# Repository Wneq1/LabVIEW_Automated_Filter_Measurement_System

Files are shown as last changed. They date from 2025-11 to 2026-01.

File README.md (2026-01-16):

# LabVIEW_Automated_Filter_Measurement_System

## 📋 Opis projektu
Projekt przedstawia system do zautomatyzowanego pomiaru charakterystyk częstotliwościowych filtrów aktywnych. Sercem układu jest autorska płytka PCB zaprojektowana w programie **KiCad**, zawierająca 6 różnych wariantów filtrów analogowych. System został stworzony z myślą o współpracy z aplikacją pomiarową w środowisku **LabVIEW**, co pozwala na automatyczne wykreślanie charakterystyk amplitodowo-fazowych.

## 🛠️ Architektura Sprzętowa (Hardware)

### 1. Sekcja Filtrów (Topologia Sallen-Key)
Na płytce znajduje się 6 filtrów aktywnych drugiego rzędu (2nd order). Wykorzystanie różnych wartości dobroci ($Q$) pozwala na demonstrację trzech klasycznych aproksymacji:

* **Bufory wejściowe (Wtórniki):** Zapewniają wysoką impedancję wejściową, eliminując wpływ impedancji źródła na parametry filtracji.
* **Filtry Dolnoprzepustowe (LPF) i Górnoprzepustowe (HPF):**
    * **$Q = 0.5$ (Bessel):** Filtr o najlepszej odpowiedzi impulsowej (brak przeregulowań) i liniowej fazie. Idealny do sygnałów prostokątnych i impulsowych.
    * **$Q = 0.707$ (Butterworth):** Filtr o maksymalnie płaskiej charakterystyce amplitudowej w paśmie przepustowym. Stanowi kompromis między szybkością opadania a odpowiedzią czasową.
    * **$Q = 2.0$ (Czebyszew):** Filtr o bardzo stromym zboczu opadania, ale kosztem pojawienia się pofalowań (ripple) i wzmocnienia w okolicy częstotliwości odcięcia.



Wybór konkretnej charakterystyki odbywa się poprzez przepięcie zworki na selektorze wyjściowym, co pozwala na natychmiastowe porównanie różnic w sygnale na oscyloskopie lub w programie LabVIEW.

### 2. Sekcja Filtrów Górnoprzepustowych (High-Pass)
Sekcja ta służy do tłumienia składowych o niskich częstotliwościach i przepuszczania sygnałów powyżej częstotliwości odcięcia ($f_c$). Zastosowano topologię Sallen-Key 2. rzędu, co pozwala na demonstrację wpływu dobroci ($Q$) na kształt "kolana" charakterystyki:

* **$Q = 0.5$ (Bessel )** 
* **$Q = 0.707$ (Butterworth)**
* **$Q = 2.0$ (Czebyszew)** 
     


### Porównanie parametrów konstrukcyjnych (HPF)
Wszystkie filtry oparte są na wzmacniaczu **OP07**, a różne typy odpowiedzi uzyskano poprzez precyzyjny dobór elementów biernych (zgodnie ze schematem):
* Kondensatory wejściowe (np. $C_{17}$, $C_{18}$) o wartości $10nF$.
* Rezystory ustalające dobroć (np. $R_{13} = 22k\Omega$, $R_{14} = 11k\Omega$).
### 3. Sekcja Zasilania (Power Supply)
Układ posiada zaawansowany blok zasilania, który umożliwia pracę z sygnałem zmiennym dzięki zasilaniu symetrycznemu:
* **Przetwornica DC-DC:** Użycie modułu **MGJ2D051515SC** pozwala na uzyskanie izolowanego napięcia symetrycznego $\pm 5V$  z pojedynczego wejścia DC.
* **Filtrowanie LC:** Zastosowanie dławika $L_1$ oraz kondensatorów $C_3$, $C_4$ minimalizuje tętnienia napięcia z przetwornicy impulsowej.
* **Zabezpieczenia:** Dioda chroniąca przed odwrotną polaryzacją oraz diody LED sygnalizujące obecność napięcia na szynach dodatniej i ujemnej.
* 


### 4. Schemat całego układu



## 🎨 Galeria Projektu i Wizualizacja PCB

W tej sekcji przedstawiono fizyczną strukturę projektu oraz finalny wygląd urządzenia po montażu. Projekt został zoptymalizowany pod kątem minimalizacji szumów oraz przejrzystości serwisowej.

### 1. Wizualizacja 3D (Render)
Dzięki narzędziom programu KiCad, wygenerowano realistyczny model 3D płytki **Active Filters Test Board**.
* **Layout:** Komponenty zostały rozmieszczone blokowo, co ułatwia diagnostykę sygnału od wejścia (Input) do wyjścia (Output).
* **Oznaczenia:** Na warstwie opisowej (silkscreen) umieszczono logotypy Politechniki Rzeszowskiej oraz KMiSD, a także czytelne etykiety dla zworek selekcyjnych dobroci $Q$.
* **Montaż:** Wykorzystano mieszaną technologię montażu (SMT dla układów scalonych i rezystorów, THT dla kondensatorów i złączy), co zapewnia kompromis między miniaturyzacją a łatwością modyfikacji.
  


### 2. Widok Warstwy Górnej (Top Layer)
Warstwa górna odpowiada głównie za prowadzenie sygnałów o wysokiej impedancji oraz zasilania wzmacniaczy operacyjnych:
* **Separacja Sygnałów:** Ścieżki sygnałowe są prowadzone w sposób możliwie najkrótszy, aby uniknąć zbierania zakłóceń elektromagnetycznych (EMI).
* **Blok Zasilania:** Wyraźnie wydzielona sekcja z przetwornicą **MGJ2D051515SC** i filtrem LC, która zasila całą płytkę napięciem symetrycznym $\pm 5V$.
* **Pola Masowe:** Wolne przestrzenie zostały wypełnione wylewką masy (Ground Plane), co poprawia stabilność pracy filtrów o wysokiej dobroci $Q=2.0$.
  


### 3. Widok Warstwy Dolnej (Bottom Layer)
Warstwa dolna pełni kluczową rolę w zapewnieniu integralności sygnałowej:
* **Ekranowanie:** Ciągła płaszczyzna masy na dolnej warstwie minimalizuje pętle masy i redukuje szumy przenoszone z sekcji zasilania impulsowego do czułych sekcji filtrów analogowych.
* **Przelotki (Vias):** Strategicznie rozmieszczone przelotki zapewniają niską impedancję połączeń między warstwami zasilania.
  


## 💻 Integracja z LabVIEW
W przyszłości projekt zostanie rozbudowy o automatyzacjie. Program w LabVIEW będzie obejmował:
1.  Sterowanie generatorem sygnałowym (częstotliwość sweep).
2.  Akwizycję danych przez kartę DAQ lub oscyloskop.
3.  Przetwarzanie danych i wizualizację charakterystyki amplitudowo-częstotliwościowej w czasie rzeczywistym.

## 🗂️ Struktura Repozytorium
* `/KiCad` - Pliki projektu PCB (schemat, layout, biblioteki).
* `/LabVIEW` - Pliki źródłowe programu pomiarowego (.vi).
* `/Documentation` - Dokumentacja techniczna i obliczenia filtrów.

---
*Projekt zrealizowany na Politechnice Rzeszowskiej (Katedra Metrologii i Systemów Diagnostycznych).*

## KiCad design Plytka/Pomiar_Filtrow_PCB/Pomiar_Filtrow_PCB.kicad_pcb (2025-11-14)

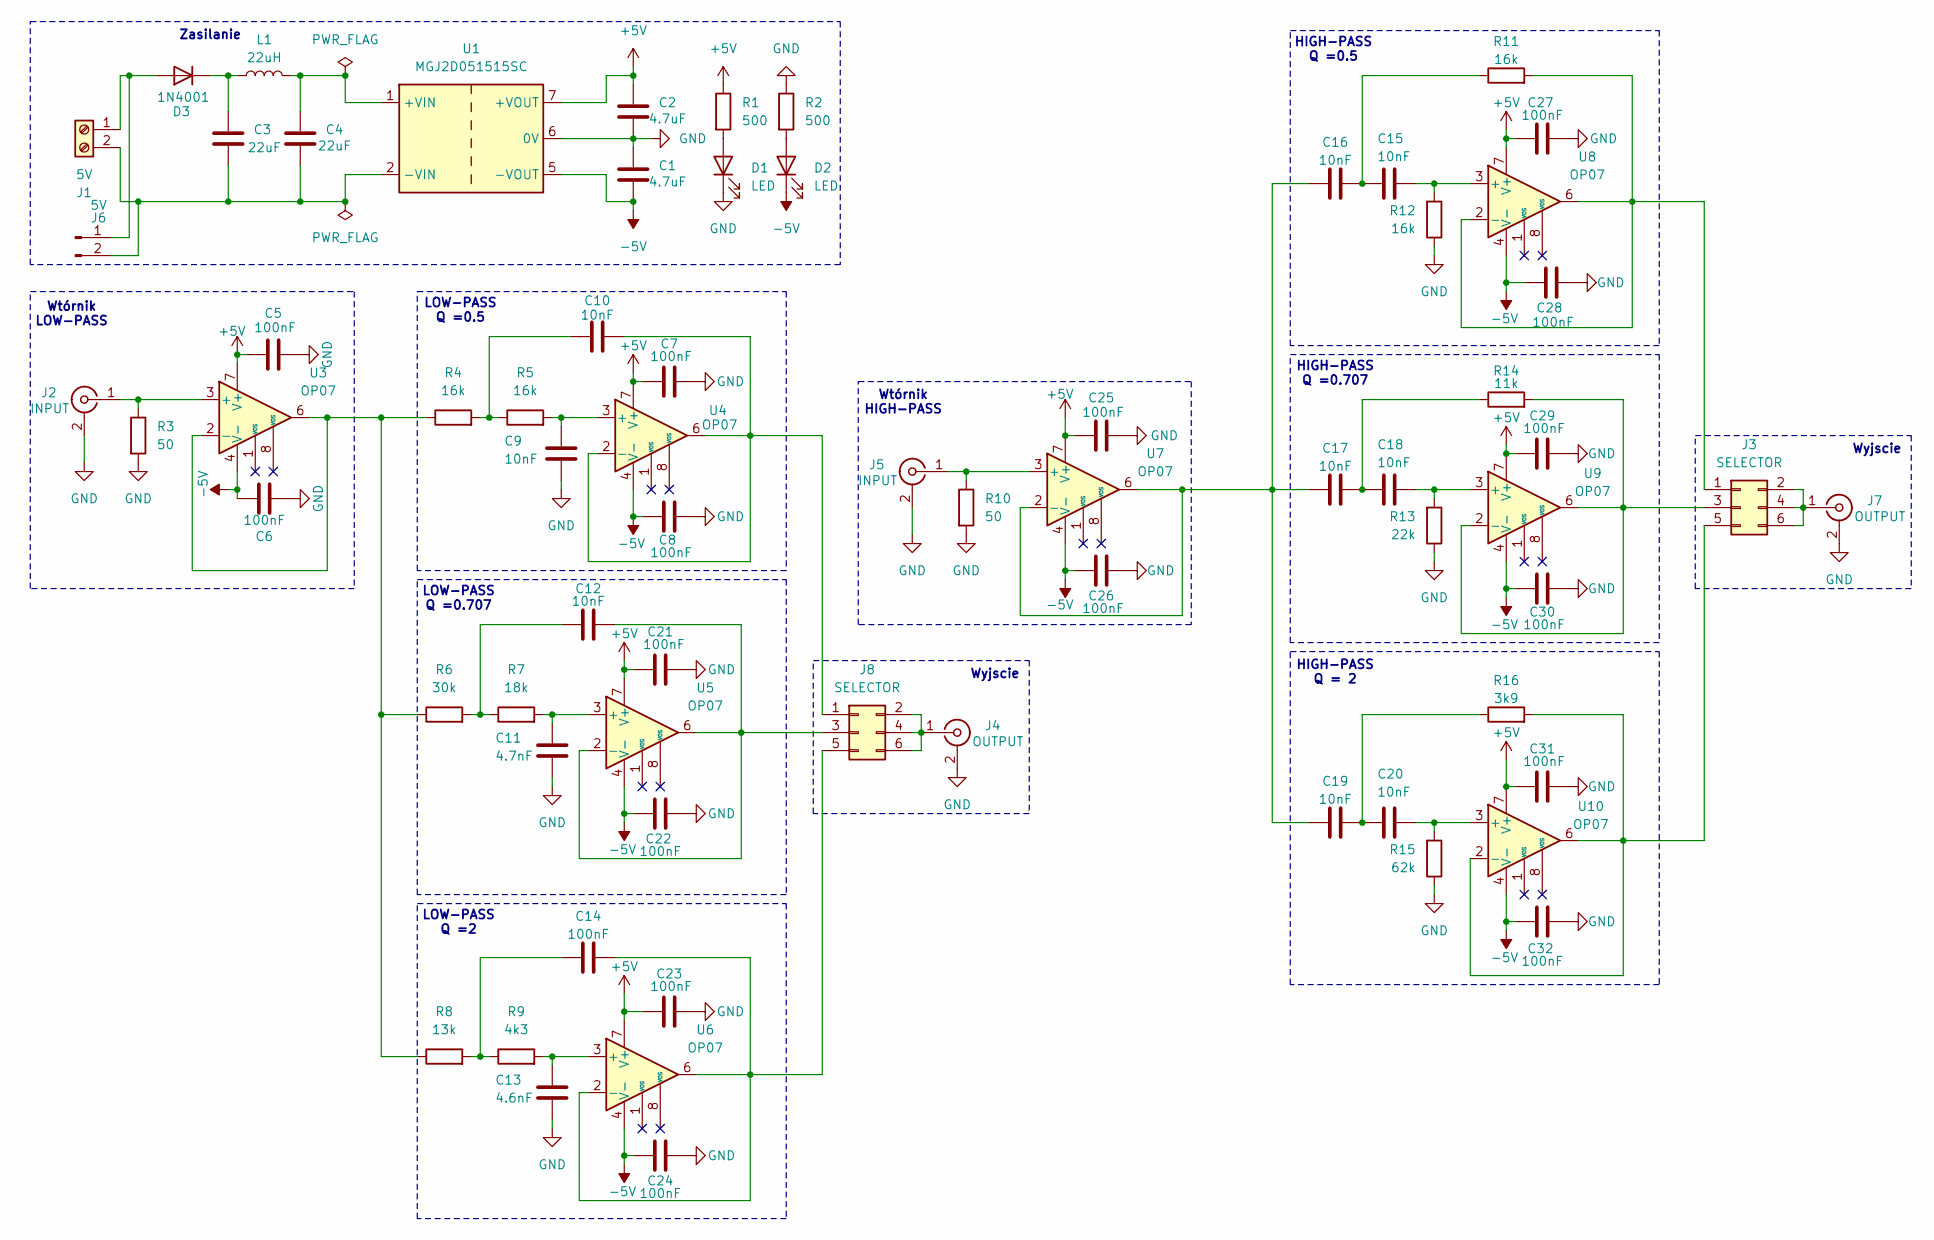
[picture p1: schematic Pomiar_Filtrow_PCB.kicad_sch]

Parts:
C1, C2: 4.7uF; C_Disc_D5.1mm_W3.2mm_P5.00mm
C3, C4: 22uF; C_Disc_D5.1mm_W3.2mm_P5.00mm
C5, C6, C7, C8, C14, C21, C22, C23, C24, C25, C26, C27, C28, C29, C30, C31, C32: 100nF; C_Disc_D5.1mm_W3.2mm_P5.00mm
C9, C10, C12, C15, C16, C17, C18, C19, C20: 10nF; C_Disc_D5.1mm_W3.2mm_P5.00mm
C11: 4.7nF; C_Disc_D5.1mm_W3.2mm_P5.00mm
C13: 4.6nF; C_Disc_D5.1mm_W3.2mm_P5.00mm
D1, D2: LED; LED_D3.0mm_FlatTop
D3: 1N4001; D_DO-41_SOD81_P10.16mm_Horizontal
J1: 5V; BarrelJack_GCT_DCJ200-10-A_Horizontal
J2, J5: INPUT; BNC_Amphenol_B6252HB-NPP3G-50_Horizontal
J3, J8: SELECTOR; PinHeader_2x03_P2.54mm_Vertical
J4, J7: OUTPUT; BNC_Amphenol_B6252HB-NPP3G-50_Horizontal
J6: 5V; PinHeader_1x02_P2.54mm_Vertical
L1: 22uH; L_Axial_L5.3mm_D2.2mm_P10.16mm_Horizontal_Vishay_IM-1
R1, R2: 500; R_1206_3216Metric_Pad1.30x1.75mm_HandSolder
R3, R10: 50; R_1206_3216Metric_Pad1.30x1.75mm_HandSolder
R4, R5, R11, R12: 16k; R_1206_3216Metric_Pad1.30x1.75mm_HandSolder
R6: 30k; R_1206_3216Metric_Pad1.30x1.75mm_HandSolder
R7: 18k; R_1206_3216Metric_Pad1.30x1.75mm_HandSolder
R8: 13k; R_1206_3216Metric_Pad1.30x1.75mm_HandSolder
R9: 4k3; R_1206_3216Metric_Pad1.30x1.75mm_HandSolder
R13: 22k; R_1206_3216Metric_Pad1.30x1.75mm_HandSolder
R14: 11k; R_1206_3216Metric_Pad1.30x1.75mm_HandSolder
R15: 62k; R_1206_3216Metric_Pad1.30x1.75mm_HandSolder
R16: 3k9; R_1206_3216Metric_Pad1.30x1.75mm_HandSolder
U1: MGJ2D051515SC; Converter_DCDC_Murata_MGJ2DxxxxxxSC_THT
U3, U4, U5, U6, U7, U8, U9, U10: OP07; SO-8_5.3x6.2mm_P1.27mm

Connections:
+5V: C2.2, C5.2, C7.2, C21.2, C23.2, C25.2, C27.2, C29.2, C31.2, R1.1, U1.7 (+VOUT), U3.7 (V+), U4.7 (V+), U5.7 (V+), U6.7 (V+), U7.7 (V+), U8.7 (V+), U9.7 (V+), U10.7 (V+)
-5V: C1.1, C6.2, C8.2, C22.2, C24.2, C26.2, C28.2, C30.2, C32.2, D2.1 (K), U1.5 (-VOUT), U3.4 (V-), U4.4 (V-), U5.4 (V-), U6.4 (V-), U7.4 (V-), U8.4 (V-), U9.4 (V-), U10.4 (V-)
GND: C1.2, C2.1, C5.1, C6.1, C7.1, C8.1, C9.2, C11.2, C13.2, C21.1, C22.1, C23.1, C24.1, C25.1, C26.1, C27.1, C28.1, C29.1, C30.1, C31.1, C32.1, D1.1 (K), J2.2 (Ext), J4.2 (Ext), J5.2 (Ext), J7.2 (Ext), R2.1, R3.2, R10.2, R12.1, R13.1, R15.1, U1.6 (0V)
unnamed: C10.1, R4.2, R5.1
unnamed: C12.1, R6.2, R7.1
unnamed: C14.1, R8.2, R9.1
unnamed: C15.2, C16.2, R11.1
unnamed: C17.2, C18.2, R14.1
unnamed: C19.2, C20.2, R16.1
unnamed: D1.2 (A), R1.2
unnamed: D2.2 (A), R2.2
unnamed: D3.2 (A), J1.1, J6.1
unnamed: C3.2, D3.1 (K), L1.1
unnamed: C3.1, C4.1, J1.2, J6.2, U1.2 (-VIN)
unnamed: J2.1 (In), R3.1, U3.3 (+)
unnamed: J3.1, R11.2, U8.2 (-), U8.6
unnamed: J3.2, J3.4, J3.6, J7.1 (In)
unnamed: J3.3, R14.2, U9.2 (-), U9.6
unnamed: J3.5, R16.2, U10.2 (-), U10.6
unnamed: J4.1 (In), J8.2, J8.4, J8.6
unnamed: J5.1 (In), R10.1, U7.3 (+)
unnamed: C10.2, J8.1, U4.2 (-), U4.6
unnamed: C12.2, J8.3, U5.2 (-), U5.6
unnamed: C14.2, J8.5, U6.2 (-), U6.6
unnamed: C4.2, L1.2, U1.1 (+VIN)
unnamed: R4.1, R6.1, R8.1, U3.2 (-), U3.6
unnamed: C9.1, R5.2, U4.3 (+)
unnamed: C11.1, R7.2, U5.3 (+)
unnamed: C13.1, R9.2, U6.3 (+)
unnamed: C16.1, C17.1, C19.1, U7.2 (-), U7.6
unnamed: C15.1, R12.2, U8.3 (+)
unnamed: C18.1, R13.2, U9.3 (+)
unnamed: C20.1, R15.2, U10.3 (+)

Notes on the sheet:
Wyjscie
LOW-PASS Q =2
LOW-PASS Q =0.707
Zasilanie
Wtórnik HIGH-PASS
HIGH-PASS Q =0.5
HIGH-PASS Q = 2
HIGH-PASS Q =0.707
LOW-PASS Q =0.5
Wtórnik LOW-PASS

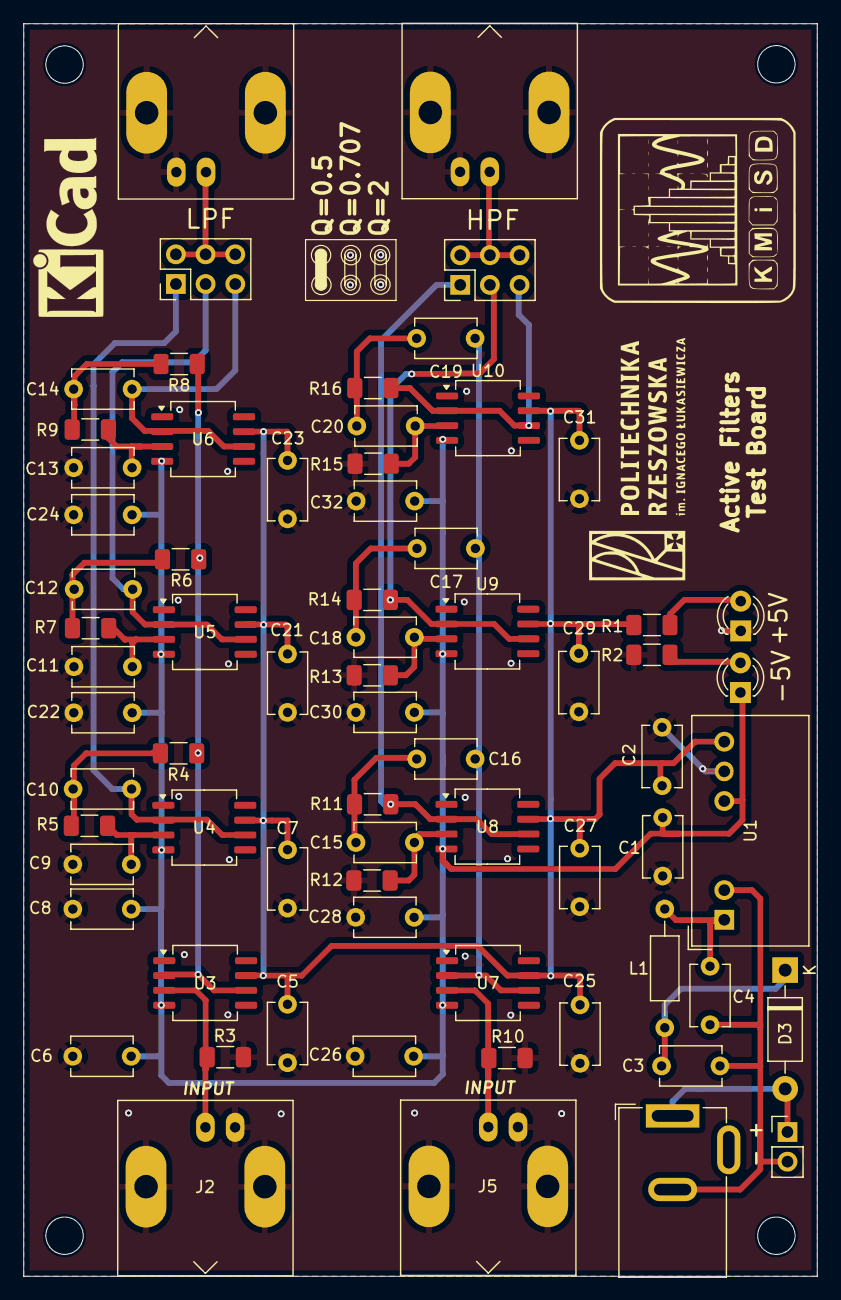
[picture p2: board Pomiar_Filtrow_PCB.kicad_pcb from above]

Board: 2 copper layers, 67.9 x 107.2 mm, 69 parts (0 on the bottom side), 33 nets.

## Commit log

2025-11-14 Create PCB
2026-01-16 Enhance README with filter and power supply details
    Added detailed descriptions for filter sections and power supply in the README.
